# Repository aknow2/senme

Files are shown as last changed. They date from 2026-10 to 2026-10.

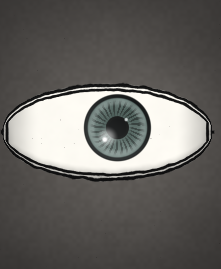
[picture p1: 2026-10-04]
simulator/images/s1/flipbook-frame-024.png

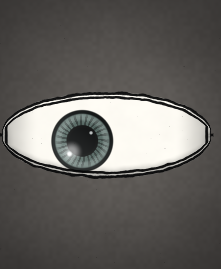
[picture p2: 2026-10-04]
simulator/images/s1/flipbook-frame-028.png

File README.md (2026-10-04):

# Senme

Senmeの機構設計・ファームウェアと、球体リソファン作成用のsimulatorをまとめたフォルダです。

- ルートの `.scad`・`.stl`・画像、`BOSL2/`、`octagonal_bell/`、`firmware/` などは `../6ro_art/senme` からコピーしています。
- `simulator/` は `../360li/experimental` を元にした独立したWebアプリです。必要な共通コード・依存関係の設定・テストをすべて内包しています。

## simulatorの起動

```sh
cd simulator
npm ci
npm run dev
```

http://127.0.0.1:5174/ を開いてください。詳しい操作・確認方法は [simulator/README.md](simulator/README.md) を参照してください。

## 機構設計とファームウェア

OpenSCADの設計は同梱の `BOSL2/` を使用します。
ファームウェアの操作・書き込み方法は [firmware/README.md](firmware/README.md) を参照してください。

## 公開対象と通信の注意

実機MACアドレスのメモ、ビルド成果物、STL、作業用の `tmp/`・`output/`、秘密情報を含むローカル設定は公開対象外です。BOSL2のライセンスは [BOSL2/LICENSE](BOSL2/LICENSE) を参照してください。

現在のESP-NOW通信には暗号化・送信元認証がなく、ブロードキャストの開始指令も受け付けます。無線が届く第三者の指令で待機中のモーターが始動する可能性があります。

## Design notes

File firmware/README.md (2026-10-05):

# SENME ESP32 コントローラー

各モードの現行動作・時間配分・操作仕様は[動作仕様書](動作仕様書.md)を参照してください。

MPU6050の揺れでESP-NOWの `START` を送る別ESP32用スケッチは
[sense_sender](sense_sender/README.md) を参照してください。
書き込みは `./firmware/flash.sh --target sense_sender --port <送信側ポート>` で実行できます。

LEDライトとブラシ付きDCモーターを、それぞれNチャネルMOSFETで制御するArduinoスケッチです。
対象は **通常のESP32（ESP32-WROOM搭載DevKit等）／Arduino-ESP32 3.x** です。
使用ボードは [ELEGOO ESP-32 開発ボード USB-C／CP2102・2個セット（B0FT2SJH3H）](https://www.amazon.co.jp/dp/B0FT2SJH3H) です。
商品写真のESP32-WROOM系モジュールとD25・D26・D27・D32・D33の印字を確認し、既存のピン設定で対応しています。
実機確認は未実施です。ESP32-C3、S2、S3などはこのスケッチの対象外です。負荷の型番は未確定のため、電力側は以下の前提・例です。

## 動作

電源投入時は保存値を読み、ESP-NOWの受信待機から開始します。ボタンを短押しして離すたびに、
「シーケンス → 編集1 → 編集2 → ESP-NOW → シーケンス」の順で切り替わります。
シーケンスへ戻る際も①から再開します。シーケンス・ESP-NOWモード中のロータリー操作は無効です。

| 区間 | 時間 | LED | モーターPWM出力率 |
| --- | --- | --- | --- |
| ① | 20秒 | 5秒周期のsin波で0→100→0%。4周期 | 0% |
| ② | 15秒 | 明るさ0%から100%へ直線的にフェードイン | 55%から設定値まで直線的に上昇 |
| ③ | 60秒 | 設定した点灯時間で点滅 | 設定値を維持 |
| ④ | 15秒 | 設定した点灯時間で点滅（補完した仕様） | 設定値から55%まで直線的に下降し、最後に即0% |

合計110秒で①へ戻ります。④の終了でモーター出力を0%・LEDを消灯し、直ちに①の0%から明滅を再開します。追加の消灯待機時間はありません。
①の式は `輝度 = (1 - cos(2π × 経過時間 / 5秒)) / 2` で、位相をずらしたsin波です。

開始時はPWM出力を55%にし、15秒かけて設定最大値へ上げます。設定最大値が55%以下の場合は、その設定値を開始時から維持します（0%設定なら出力しません）。この開始処理はシーケンス・Motor Edit・ESP-NOWに共通です。

### 編集1：LEDの点灯時間

- 周期は55.55ms固定（約18.0018Hz）。厳密な18Hzの周期は約55.5556msですが、指定の55.55msを使用しています。
- 時計回り1クリックで点灯時間を0.5ms増加、反時計回りで0.5ms減少します。
- 範囲は0〜55.55ms。0msは消灯、55.55msは連続点灯、その間は100%の明るさでパルス点灯します。
- 例えば5.0msなら「5.0ms点灯＋50.55ms消灯」です。変えるのは点滅の周期ではなく、周期内の点灯時間です。
- 初期値は5.0ms。モーター出力は0%です。

点灯時間は0.5ms刻みで55.5msまで調整でき、その次が連続点灯の55.55msです。旧設定の56ms連続点灯は読み込み時に55.55msへ移行します。

### 編集2：モーター最大出力

- 時計回り1クリックで1%増加、反時計回りで1%減少します（刻み幅の補完仕様）。範囲は0〜100%、初期値は55%です。
- 入ってから15秒で55%から設定値へ加速します。ロータリー操作は設定値へ反映し、加速中は経過時間に応じた割合を出力します。
- 終了時は現在の出力から15秒かけて55%まで下げ、その後すぐ0%にします。停止完了までSTART受信・モード切替は無効です。
- LEDは加速中の15秒間は明るさ0%から100%へ直線的にフェードインし、加速完了後に編集1の設定で点滅します。
- 出力率は回転数ではありません。低出力で始動しない場合や、負荷によって回転数が変わる場合があります。

### ESP-NOW：実行メッセージで60秒動作

編集2からボタンを短押しすると、LEDを点滅させたまま15秒かけてモーターを減速してからOFFにします。停止完了後にSTART受付を開始し、LEDはシーケンス①と同じ5秒周期のフェードイン・フェードアウトを繰り返して待機します。
フェードは明るさ0%から開始し、30秒を超えてもSTARTを受信するまで継続します。
起動時もESP-NOW待機に入り、STARTを受信するまでモーターは停止したままです。ESP-NOW以外のモードでは実行メッセージを破棄します。

| 受信後の区間 | モーターPWM出力率 | LED | 実行メッセージ |
| --- | --- | --- | --- |
| 0〜15秒 | 55%から編集2の設定値まで直線的に上昇 | 明るさ0%から100%へ直線的にフェードイン | 破棄 |
| 15〜45秒 | 設定値を維持 | 編集1の設定で点滅開始 | 破棄 |
| 45〜60秒 | 設定値から55%まで直線的に下降し、最後に即0% | 同上 | 破棄 |
| 停止後0〜3秒未満 | 0%で待機 | 明るさ0%から5秒周期のフェードを再開 | 破棄 |
| 停止後3秒以降 | 0%で待機 | フェードを継続 | 次の実行を受付 |

加減速を含めて合計60秒です。START受信後はシーケンス①の20秒間の明滅を挟まず、直ちに加速へ移ります。
待機中の有効なメッセージ1件だけを処理し、動作中のメッセージを
後から実行するために蓄積しません。受信コールバックでは待機状態を確認してから本文を調べ、
動作中は本文の解析も行いません。無線自体は有効なままで、アプリケーション側で破棄します。

メイン処理がモーターPWMを0%にし、LEDをフェードへ切り替えた時点から3秒間はSTARTを破棄し、その後に受付を再開します。この間のSTARTは予約しません。起動時とMotor Editからの移行時には、この3秒待機を設けません。停止後の3秒間も短押しでシーケンスへ移れます。
実際の軸の停止を検知しているわけではなく、惰性で回る可能性があります。
動作中のボタン短押しは無効です。待機に戻ったら短押しでシーケンスへ移れます。
ESP-NOWモードではロータリー操作・長押し保存は無効で、編集1・2の設定を使用します。

#### 送信側の設定

- Wi-Fiチャンネル：**1**（スケッチの `ESPNOW_CHANNEL` で変更可能）。送受信側を同じチャンネルにします。
- 宛先：起動ログの `ESP-NOW: MAC=...` に表示される受信側STA MACアドレス。
- メッセージ：ASCIIの **`START`**、5バイト。終端NULを含む6バイトも許可します。
  改行付き、JSON、小文字の `start`、その他のデータは実行しません。
- 暗号化なし。送信側では宛先をESP-NOW peerに登録して送ります。ブロードキャストも受け付けます。
  送信元MACの制限やアプリケーションの実行受付ACKはありません。
- ルーターへの接続は不要です。USBモニターは引き続き `dtr=off,rts=off` を使用します。

送信側でWi-Fi／ESP-NOWの初期化・同一チャンネル設定・宛先peer登録が済んでいる場合の送信例：

```cpp
const uint8_t command[] = {'S', 'T', 'A', 'R', 'T'};
esp_now_send(receiverMac, command, sizeof(command));
```

送信成功の通知だけでは、受信側が動作を開始したとは判断できません。
受信側が動作中なら破棄されます。また、待機に戻った後に届く再送は新しい実行要求になります。

シリアルログは `READY` → `RUNNING (60 seconds)` →
`STOPPED; COOLDOWN (3 seconds; START ignored)` → 3秒後に `READY (waiting for START)` の順で表示されます。

参考：[Espressif ESP-NOW API](https://docs.espressif.com/projects/esp-idf/en/v5.5/esp32/api-reference/network/esp_now.html)。

### 3秒長押しで保存

編集モードで3秒押し続けると、そのモードの設定だけを内蔵フラッシュへ1回保存します。
離してもモードは切り替わりません。シーケンス・ESP-NOWモード中の長押しは無効です。
保存せずに変更した値も、電源が入っている間はモードをまたいで使用します。
再起動すると最後に保存した値へ戻ります。

ESP32向けの `Preferences`（NVS）をEEPROMの代わりに使います。追加のEEPROM部品は不要です。
保存成功時はシリアルモニターに `SAVED`、失敗時は `SAVE FAILED` を表示します。
保存成功時はLEDを明るさ100%で約3Hz、1秒間に3回点滅させます（約167ms点灯／約167ms消灯）。終了後は現在のモードのLED表示へ戻ります。保存失敗時は確認点滅を行いません。確認点滅中もモーター制御は継続します。

## 配線例

スケッチ先頭の定数でピン番号を変更できます。各GPIOは3.3V信号です。

| ESP32端子 | ELEGOO基板の印字 | 接続先 |
| --- | --- | --- |
| GPIO25 | D25 | LED用MOSFETのゲートへ100〜330Ωの直列抵抗を介して接続 |
| GPIO26 | D26 | モーター用MOSFETのゲートへ100〜330Ωの直列抵抗を介して接続 |
| GPIO32 | D32 | エンコーダーA / CLK |
| GPIO33 | D33 | エンコーダーB / DT |
| GPIO27 | D27 | エンコーダーボタン / SW |
| GND | GND | 各MOSFETソース、負荷電源マイナス、エンコーダーCOM、ボタンの反対端 |
| 3.3V | 3V3 | 電源端子のあるエンコーダーモジュールのVCC（3.3V対応品） |

番号は基板の端から数えた位置ではなくGPIO番号です。例えばコードの `25` は基板の `D25` に対応します。
モード切替にはエンコーダーに付属するボタンを使います。基板上の `BOOT`・`EN` ボタンとは別です。

LEDとモーターの各負荷について、`負荷電源＋ → 負荷＋ → 負荷− → MOSFETドレイン` と接続します。
MOSFETソースはGNDへ、ゲート–ソース間には10kΩ程度のプルダウン抵抗を入れ、起動中もOFFに保ちます。
MOSFETは **ゲート電圧2.5〜3.3Vでのオン抵抗が仕様に明記されたもの** を、負荷電流・電圧・発熱に合わせて選定してください。
しきい値電圧だけでは選定できません。PWM対応MOSFETモジュールを使う場合も、3.3V入力・HIGHでONの仕様を確認します。

モーター両端には逆起電力を逃がすフライバックダイオードを並列接続します。
**カソード（帯側）はモーター＋、アノードはモーター−（ドレイン側）** です。
モーターの始動・拘束電流に対応する電源、MOSFET、ダイオードが必要です。
モーターの電力配線はESP32基板を経由させず、電源付近でGNDを共通化します。
電源付近のバルクコンデンサとモーター端子間のノイズ対策コンデンサも、使用モーターに合わせて設けてください。

LEDは電流制限付きのDCライト／LEDストリップを想定しています。裸のLEDやパワーLEDには適切な電流制限回路が別途必要です。
LED・モーターの負荷電力はESP32のGPIOや3.3V端子から供給しません。
この配線はブラシ付きDCモーター用です。サーボ・ステッピング・ブラシレスモーターには別の駆動回路が必要です。

エンコーダー入力は内部プルアップを使用し、接点がGNDへ落ちる方式です。5Vにプルアップされた信号を直接接続しないでください。
時計回りで値が減る場合は `ENCODER_DIRECTION = -1` に変更します。
2クリックで1回しか変わらない機種では `ENCODER_EDGES_PER_CLICK` を4から2へ変更します。

## Arduino CLIでの書き込み（macOS）

対象は `ESP32 Dev Module`、FQBNは `esp32:esp32:esp32` です。
Arduino-ESP32はコンパイル確認済みの **3.3.8** を使用します。
追加ライブラリは不要です。Preferences、LEDC、RMT、Wi-Fi、ESP-NOWはESP32コアに含まれます。

### 自動実行スクリプト

リポジトリのルート（`senme`）から実行します。
先にLED・モーターの負荷電源を切り、ESP32をUSB接続してください。
開いているシリアルモニターは `Ctrl+C` で終了します。

```sh
./firmware/flash.sh --port /dev/cu.usbserial-0001
```

スクリプトはArduino CLIの準備 → ESP32コア3.3.8の準備 → コンパイル → 書き込み →
シリアルモニター起動を順に実行します。CLIがない場合は、インストール済みのHomebrewを使用します。
コアが既に3.3.8なら再インストールしません。ポートは実機に合わせて指定してください。
別の作業ディレクトリから実行しても動作します。

```sh
# ポート一覧の確認
arduino-cli board list

# 書き込みまで実行し、モニターを開かない
./firmware/flash.sh --port /dev/cu.usbserial-0001 --no-monitor

# 実機に書き込まず、環境準備とコンパイルだけ実行
./firmware/flash.sh --build-only

# 環境変数でポートを指定することも可能
export ESP32_PORT=/dev/cu.usbserial-0001
./firmware/flash.sh
```

### 手動で実行する場合

1. 初回のみCLIとボード定義を準備します。CLIが導入済みなら `brew install` は不要です。

```sh
brew install arduino-cli
arduino-cli config add board_manager.additional_urls \
  https://espressif.github.io/arduino-esp32/package_esp32_index.json
arduino-cli core update-index
arduino-cli core install esp32:esp32@3.3.8
```

2. USB接続したボードのポートを確認します。ボード名がUnknownでも、ポートとFQBNを指定できます。

```sh
arduino-cli board list
export ESP32_PORT=/dev/cu.usbserial-0001
```

3. `senme` ディレクトリからコンパイル・書き込みします。
   `senme_controller.ino` と `Control.h` は同じフォルダに置きます。

```sh
arduino-cli compile \
  --fqbn esp32:esp32:esp32 \
  --output-dir /tmp/senme-build \
  firmware/senme_controller

arduino-cli upload \
  --port "$ESP32_PORT" \
  --fqbn esp32:esp32:esp32 \
  --input-dir /tmp/senme-build \
  firmware/senme_controller
```

4. **115200 bps・DTR OFF・RTS OFF** でログを開きます。

```sh
arduino-cli monitor \
  --port "$ESP32_PORT" \
  --config baudrate=115200,dtr=off,rts=off
```

接続後に基板の **EN（RESET）を一度押して離す**と、起動ログを確認できます。
BOOTは押しません。初期設定では次の表示が出ます（保存済みの設定があれば数値は変わります）。

```text
Mode: ESP-NOW; click: next mode; hold 3 seconds in edit mode: save
LED: 5.00 ms ON / 55.55 ms period; motor maximum: 55%
ESP-NOW: READY (waiting for START)
```

モニター終了は `Ctrl+C` です。起動後はSTART受信でモーターの加速が始まるため、
配線を確認してから負荷電源を入れてください。

### 文字化け・接続失敗時

- 実機では `baudrate=115200` だけの指定で文字化けし、
  `baudrate=115200,dtr=off,rts=off` の指定とリセットでログ表示を確認できました。
  スケッチ側も `Serial.begin(115200)` です。文字化け時は上記設定で開き直し、ENを押してください。
- 書き込みが `Connecting...` で止まる場合は、BOOTを押したまま書き込みを開始し、転送開始後に離してください。
- ポートがない場合はUSBデータ通信対応ケーブルと接続を確認し、`arduino-cli board list` で再確認してください。
- ポート使用中のエラーが出る場合は、別のターミナルやArduino IDEのシリアルモニターを終了してください。

参考：[Espressifのボード定義の導入手順](https://docs.espressif.com/projects/arduino-esp32/en/latest/installing.html)、
[DTR／RTSと起動・リセットの関係](https://docs.espressif.com/projects/esptool/en/latest/esp32/advanced-topics/boot-mode-selection.html)。

## 時間精度と実機確認

LED点滅はRMTの1MHzタイマーで周期55,550tick、点灯時間500tick刻み（最大55,550tick）として生成します。点灯区間は100%出力とし、キャリアPWMは無効にしています。
設定保存やシリアル表示中もハードウェアが波形を出し続けます。①の調光は1kHzのPWMを使います。
調光と点滅の切替時には、周期・比較値の反映待ちで約55.55ms消灯します。周期自体の精度はボードのクロック精度に依存します。
設定・明るさの更新時は波形を一度停止して新しい周期を開始します。切替時のパルスは短くなる場合があります。一定設定ではハードウェアが自動反復し、保存や通信によるタイミングの揺れを避けます。
モーターは20kHz・10bit PWMです。モード切替と加減速の更新はメインループで行うため、OSのスケジューリング等による遅延があります。

MOSFET1個による制御では出力を0%にしてもモーターは惰性で回転することがあります。
「減速終了後に実際の回転停止を確認してLEDを消す」ことまで必要な場合は、回転検出とブレーキ可能なドライバーを追加してください。
この実装では15秒の減速終了時のPWM出力0%を停止指令と扱っています。
すべての通常停止（シーケンス・ESP-NOW・編集2終了・シーケンスから編集1への切替）は、現在の出力から15秒でPWM出力率55%へ下げ、最後に即0%とします。
開始時の出力が55%以下なら出力を上げずに15秒維持してから0%にします。既に0%ならそのまま停止します。
LED・モーター制御APIなどでエラーが発生した場合も、最後に正常適用した出力から15秒かけて55%へ減速し、その後0%を指令します。55%以下は15秒維持し、既に0%またはモーター未初期化なら直ちにOFFを指令します。異常時はSTART受付を無効化し、停止処理後も自動復帰せずリセット待ちになります。モーターAPI自体の失敗時は減速を保証できず、その旨をログに表示します。最後の0%指令に失敗した場合は、1秒ごとに0%を再試行します。電源断・CPU停止はこの減速処理の対象外です。

- 起動直後はESP-NOW待機となり、モーター出力0%、LEDが5秒周期で明滅し、START未受信なら20秒を超えても停止を維持すること。
- 待機中の短押しでシーケンス①に入り、LEDが5秒周期で4回明滅すること。
- シーケンスへ切り替えてから20秒で加速開始（LEDは15秒で0%から100%へフェードイン）、35秒で設定出力に達して点滅開始、95秒で減速開始、110秒で出力0%になり①へ戻ること。
- シーケンスから編集1へ切り替えると15秒で55%まで減速後、即0%になること。減速中の再切替は無効になること。
- オシロスコープ等で55.55ms周期と0.5ms刻みの点灯時間を確認すること。0msと55.55msの端点も確認すること。
- 編集2の開始時は15秒で加速し、終了時は15秒で55%まで減速して即0%になること。減速中のSTARTは破棄されること。
- 編集2で出力が1%刻みで変わり、0〜100%に収まること。低出力時の始動・発熱も確認すること。
- 長押しで `SAVED` が1回出て、LEDが100%で1秒間に3回点滅して元の表示へ戻ること。離してもモードが変わらず、点滅中もモーター制御が続くこと。保存失敗時は確認点滅しないこと。
- 各設定を保存して電源を入れ直すと復元されること。未保存変更は復元されないこと。
- モーター駆動中にエンコーダーの誤カウントやESP32の再起動が起きないこと。
- ESP-NOW待機中はLEDだけが5秒周期でフェードし、30秒を超えてもモーターが動かないこと。停止直後にフェードを再開し、STARTは3秒間破棄した後に受付を再開すること。
- ESP-NOWモードで `START` を送り、15秒加速・30秒維持・15秒減速（55%到達後、即0%）して停止すること。
- 動作中に繰り返し送信しても、延長・再実行されないこと。送信をやめて待機へ戻っても勝手に再開しないこと。
- 待機に戻ってから新しい `START` を送ると再び実行すること。他モードや不正なメッセージでは開始しないこと。
- ESP-NOW動作中の短押しでモードが変わらず、待機中なら切り替えられること。
- 無線通信中もLEDの周期、モーターの加減速、電源の安定性に問題がないこと。

ホスト側のロジックテストは、`firmware` フォルダで次のように実行できます。

```sh
c++ -std=c++17 -Wall -Wextra -Werror tests/control_test.cpp -o /tmp/senme-control-test
/tmp/senme-control-test
```

検証済み：Arduino-ESP32 3.3.8／`esp32:esp32:esp32` のコンパイル、および上記ロジックテスト
（シーケンス境界・加減速・設定範囲・ボタンのチャタリングと長押し・ESP-NOW実行状態／受信破棄／停止後3秒の受信抑止と再受付・時計の桁あふれ）。
実機の回転・波形・電源ノイズ・保存復元・ESP-NOW送受信は未確認です。

## 参照

- [Espressif: PreferencesはEEPROMの代替、電源断後も保持](https://docs.espressif.com/projects/arduino-esp32/en/latest/tutorials/preferences.html)
- [Espressif: LEDC API](https://docs.espressif.com/projects/arduino-esp32/en/latest/api/ledc.html)
- [Espressif: MCPWMタイマー・比較器・出力制御](https://docs.espressif.com/projects/esp-idf/en/v5.5/esp32/api-reference/peripherals/mcpwm.html)

## ボタン誤判定の調査・修正（2026-10-03）

ボタンの読み取りが途切れた間に離された短押しを、経過時間だけで長押し保存に分類する経路を再現し、修正しました。100 msを超えるサンプリング中断が操作中にあった場合、その操作を破棄し、25 ms以上の安定したリリース後に次の押下を受け付けます。中断中の押下時間は確認できないため、保存や遅延したモード切替を実行しません。

シリアルには `BUTTON: CLICK (… ms)`、`BUTTON: LONG PRESS (… ms)`、読み取り中断時には `BUTTON: sampling gap >100ms…` が出ます。短押しのつもりで `LONG PRESS (3000 ms)` が出る場合は、実際の接点・GPIOの状態も確認が必要です。この修正で実機症状の原因が確定したわけではありません。

モード切替に伴う15秒のモーター停止中、ESP-NOWの受付後〜運転終了までの短押し無効は従来仕様です。無効な操作は予約されません。`Mode change ignored…` のログでボタン判定自体の失敗と区別できます。

## モード切替のLED通知（2026-10-03）

短押しによるモード切替が成立すると、LEDが短く2回点滅します。消灯100 ms → 点灯80 ms → 消灯100 ms → 点灯80 ms → 消灯140 ms、合計0.5秒で通常の表示に戻ります。Save成功時の「約1秒で3回点滅」と区別できます。

停止中・ESP-NOW運転中などで短押しを無視した場合は、切替通知を出しません。通知はLEDだけを一時的に上書きし、モーター制御・ボタン読取り・ESP-NOW処理は継続します。通知の間もシーケンスの時間は進みます。連続して切り替えた場合は最新の通知を最初から表示し、Save通知中に切り替えた場合も切替通知へ置き換えます。

## ボタン入力の極性（2026-10-04）

実機で短押しだけを行った際、旧判定（LOWで押下）では2.4〜2.8秒のCLICKや3秒のLONG PRESS、意図しないSaveが記録されました。押していない時間を押下時間として数えている可能性が高いため、このController用の `BUTTON_PRESSED_LEVEL` を `HIGH` に変更しています。実機で短押し時間と無操作時のログを確認してください。起動ログにはGPIO27のレベルと設定した押下レベルを表示します。

GPIO27の `INPUT_PULLUP` は継続しています。通常の「押すとGNDにつながる」常開スイッチを使う場合は `BUTTON_PRESSED_LEVEL = LOW` にしてください。今回の変更は自動極性判定ではありません。

修正版をControllerへ書き込み、起動時GPIO27=LOWを確認しました。実機の短押し3回は145 ms・174 ms・197 msのCLICKとして認識され、ESP-NOW→SEQUENCE→EDIT 1→EDIT 2へ切り替わりました。この確認中にLONG PRESSやSaveの誤検出はありません。保存設定（LED 1.50 ms、モーター最大93%）は保持しています。

## 点滅時の明るさ（2026-10-04）

点滅時の明るさを100%へ戻しました。RMTのキャリアPWMは無効にし、点灯区間は連続HIGH、消灯区間はLOWです。周期55.55 msと設定点灯時間は維持します。点灯時間1.50 msでは周期全体の平均出力は約2.7%です。
開始フェードは15秒で0%→100%、モーター開始・停止は55%です。

## START受信時の始動通知

ESP-NOWのSTART受付後、モーターを停止したままLEDを1秒間に6回点滅させます。100%点灯と消灯を約83msずつ繰り返し、その後に従来の60秒運転（15秒加速・30秒維持・15秒減速）を開始します。通知中も追加STARTと短押しは無効です。ログは `START accepted; 6 flashes (1 second), motor OFF` → `RUNNING (60 seconds)` の順に表示されます。

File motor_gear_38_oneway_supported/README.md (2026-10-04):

# 旧ワンウェイクラッチ：駆動側ストッパー付きハブ

`motor_gear_38_oneway_supported_hub.stl` が交換用です。旧版の `motor_gear_38_oneway_gear.stl` と `motor_gear_38_oneway_cover.stl`、使用中の金属ねじを再利用します。鼓形ローラー版用ではありません。

## 変更点

バネ爪の自由端の背後に、中央ハブと一体の固定受けを3箇所追加しました。爪が駆動反力で時計回り側へ逃げると受けに当たる構成です。爪との初期隙間は半径24.6 mm付近で約0.34 mm（0.8度）。受けの最大半径は25.2 mmで、外ギアの内歯先端半径26 mmより0.8 mm内側です。

爪先形状、バネ厚1.2 mm、D穴、全高13 mm、蓋との隙間は旧版と同じです。回転方向も旧版と同じです。爪の内側を全面的に埋めず、半径内向きの退避空間を残しています。

## 印刷と交換

1. 交換用ハブだけPETGで印刷します。元のハブと同じ向きで、張り出し下面にサポートを使います。
2. サポートとバリを除去します。特に爪とストッパーの隙間が印刷でつながっていないことを確認します。
3. 蓋を外してハブを交換し、既存の蓋と金属ねじで組み戻します。
4. まず手で駆動方向の噛み込みと、逆方向の空転を旧版と比較します。その後、低負荷からモーター駆動時の歯飛び音を確認します。

## 確認済み範囲と限界

幾何学チェックは `verify_supported.scad` と `geometry_checks.json`、STLチェックは `mesh_checks.json` を参照してください。

- 初期位置で爪と受けが重ならないこと。
- 爪を剛体として1度時計回りにずらすと受けに当たること。
- 爪を半径内向きに0～2.2 mm平行移動させた指定経路で、受けと重ならないこと。
- 組立初期位置で、ハブと既存のギア・蓋に意図しない重なりがないこと。

**指定した剛体移動経路の確認は、実際のバネ変形や荷重解析とは異なります。** 曲がる爪が空転時にも受けに当たり、抵抗が増える可能性があります。歯飛びの改善、空転抵抗、保持トルク、疲労寿命は実機未検証です。改善しない、または空転が重くなる場合は、無理に回し続けず旧ハブと比較してください。

元のCAD・STLは変更していません。このフォルダの `motor_gear_38_oneway.scad` は旧版の参考コピーです。新しい編集対象は `motor_gear_38_oneway_supported.scad` です。歯形生成は親フォルダの `BOSL2` を参照します。STLの印刷にはBOSL2は不要です。

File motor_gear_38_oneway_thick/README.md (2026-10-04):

# 旧版ワンウェイクラッチ：バネ腕1.4mm比較用ハブ

印刷するのは `motor_gear_38_oneway_thick_hub.stl` だけです。旧版 `motor_gear_38_oneway_gear.stl`、同cover、金属ねじを再利用します。

旧版のバネ腕の幅を1.2mmから1.4mmへ増やしました。同じパラメータを使うアンカー先端も太くなります。ストッパーはありません。爪先形状、D穴、全高13mm、回転方向は元のままです。

旧版と同じ印刷姿勢で、張り出し下面にサポートを使用してください。バネ腕の周囲のサポート・バリを取り除き、取り付け後は手回しで元のハブと比較してください。

カチカチ音は歯飛び以外に、ターンテーブルの惰性による追い越し空転でも発生します。重量だけで原因は断定できません。一定速のモーターを慣性だけで持続的に追い越すわけではありませんが、モーター側が減速・速度変動した瞬間に出力側が先行することは考えられます。

正常な追い越し空転が原因なら、厚肉化は必要とは限りません。バネを太くすると空転抵抗が増える可能性があります。駆動中に中央ハブが外ギアを追い越すのか、外ギアがハブを追い越すのかを目印・動画で確認してください。改善効果・空転抵抗・耐久性は実機未検証です。

CADソースは親フォルダの `motor_gear_38.scad` と `BOSL2` を参照します。元ファイルは変更していません。

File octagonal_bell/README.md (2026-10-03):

# 正八角形の電子鈴

参考画像をもとにした試作モデル。単位は mm。OpenSCAD 2021.01 で使用でき、外部ライブラリは不要です。

## 開き方

`octagonal_bell.scad` をOpenSCADで開き、F5でプレビューします。
先頭の `part` を変更して表示を切り替えます。

| part | 表示 |
| --- | --- |
| assembly | 完成形 |
| section | 前半分を取り除いた断面・収納例 |
| exploded | 分解表示 |
| print | 印刷部品4点を平面上に配置 |
| body / lid / tray / shelf | 本体／上蓋／基板トレー／電池棚を個別表示、底面Z=0 |
| ball | 鈴玉の参考形状、底面Z=0 |

印刷には同梱の `body.stl`、`lid.stl`、`tray.stl`、`shelf.stl` を使用できます。寸法を変えた場合は各部品をF6でレンダリングしてSTLを再出力してください。完成表示の電池・基板は寸法確認用の箱です。

## 寸法と構造

- 正八角形の対辺180、対角約194.8、ロープ取り付け部を含め全高148.4（元の135から13.4延長）。
- 壁厚3、胴体の合わせ面Z=91.4、上蓋との隙間0.35、差し込み部の片側余裕0.3。
- Bodyの底面対辺は約128.3。サポートを減らすため旧100から拡大し、下部外周は八角形の頂点方向でも鉛直から45度以下の張り出しにしています。
- 電池135.5 × 69 × 16を中央の棚に横置き。棚の下にESP32 52 × 28 × 12とMPU6050 21 × 16 × 5の参考外形を横並びで配置。
- トレー上面から電池棚下面までの有効高さは30mm（`electronics_clearance`）。トレー底面Z=48を維持して電池棚下面をZ=80.4に上げ、合わせ面・肩・天井も13.4mm上げています。支柱の全高は32.4mm。基板の参考外形には実物の10mmピンやコネクター・配線を正確には反映していません。
- 下部は直径25の鈴玉用空間。基板トレーが電子機器と鈴玉を隔てます。
- 底面中央の音穴は幅4、全長90、両端の丸穴は直径10。ロープ穴は幅19 × 高さ14。
- 上蓋は前後2箇所のM3 × 35ねじと六角ナットで固定。本体側は直径3.4の通し穴と、内側から横差しできるナット受け（対辺6.0・高さ2.8）があります。ナット受け上面は合わせ面から19mm下（Z=72.4）、下面は21.8mm下（Z=69.6）です。外装の外側には開口しません。
- 電池棚は4箇所のM3ねじと六角ナットでトレーの支柱に固定。支柱はトレー底面まで直径3.4の貫通穴、裏面には対辺6.0・深さ2.6の六角ナットくぼみがあります（各部のナットは対辺5.5・厚さ2.4を想定）。

画像の対辺150では、厚さ3の壁と矩形の電池の角の間に余裕がありません。現在のモデルは対辺180に設定しています。電池外形は八角形に収まりますが、コネクター・ケーブルの曲げ・ケースの突起は含めていません。実物に応じて `battery` と `body_width` を調整してください。基板寸法・高さも仮定値です。

## 組み立て

1. トレー・電池棚を入れる前に、本体の前後の固定部へ内側の横穴からM3六角ナットを1個ずつ奥まで差し込み、ねじ穴を合わせます。ナット受けは電池棚より下にあるため、先に入れてください。その後、本体に直径25程度の鈴玉を入れます。
2. 基板を絶縁スペーサーや結束バンドでトレーに固定します。基板固有の取り付け穴は未設定です。
3. 本体に入れる前に、トレー裏面の4箇所の六角くぼみにM3ナットを入れ、電池棚の上からねじを通して支柱に固定します。棚上面からトレー裏面までは34.8mmです。頭の下から測って35mmのM3ねじ（皿ねじ以外・座金なし）なら裏面から約0.2mm突き出す設計です。実物のナット・ねじとの適合を確認してください。くぼみの余裕は `tray_nut_af` と `tray_nut_depth` で調整できます。
4. 棚を固定したトレーを本体内周の受けに載せます。
5. 電池を棚の長穴を使った結束バンドで固定し、奥側のケーブル口から配線します。
6. 上蓋の差し込み部を入れ、頭径6.6未満のM3 × 35で固定します（皿ねじ以外・座金なし）。ねじ先端は合わせ面から23mm下まで入り、ナット受け下面を1.2mm通過します。閉じるまでナットが横穴から抜けないよう本体を水平に保ってください。挿入余裕は `lid_nut_af` と `lid_nut_height` で調整できます。
7. ロープを上部の穴に通します。

トレー自体は受けに載せる方式です。振ったときの浮きやがたつきは試作確認の対象で、必要なら蓋側との間に緩衝材を追加してください。

30mmの隙間に変更する前の本体は高さが足りないため、新しいトレーと組み合わせる場合は本体も再印刷してください。トレー受けの高さと鈴玉の空間は維持しています。底に置いた参考鈴玉の上端とトレー下面の隙間は20mmです。

## 印刷と確認範囲

### 必要なねじ・ナット

| 用途 | 部品 | 数量 |
| --- | --- | --- |
| 上蓋と本体 | M3 × 35 なべ小ねじ（全ねじ、頭径6.6未満） | 2本 |
| 電池棚とトレー | M3 × 35 なべ小ねじ（全ねじ） | 4本 |
| 上蓋2箇所＋トレー4箇所 | M3六角ナット（対辺5.5・厚さ2.4想定） | 合計6個 |

M3 × 35なべ小ねじ6本とM3六角ナット6個に統一しています。座金なしで設計しています。ESP32・センサーの固定ねじは、基板の取り付け穴が未確定のため含みません。ナット式の上蓋固定に変更する場合、本体は新しい `body.stl` で印刷してください。

本体・トレー・棚はSTLの向きで底面を下にします。蓋はスライサーで差し込みリップ、天井、ロープ穴の下面を確認し、必要なサポートを付けてください。全パーツのサポート不要は保証していません。

### Bodyのサポートなし印刷向け変更（2026-09-26）

今回の変更はBodyのみです。蓋・トレー・電池棚の形状とSTLは変更していません。既存のM3×35ねじ・ナットを使い、Bodyだけ差し替えられます。

- トレー受けの下面に高さ6mmの斜面を追加。受け上面Z=48と受け幅を維持しています。
- 蓋用ネジ支柱の下端を壁から伸びる斜面に変更。ネジ位置、支柱上部の直径12mm、ナット挿入口の位置を維持しています。
- ナット穴の天井には0.3mmずつ2段の逃げを追加。最初は左右へ最大6mm、次は前後へ3.4mmを橋渡ししてから丸いネジ穴へつなぎます。ナットを受ける前後の平らな座面を残し、除去が必要な膜は設けていません。
- 底面の対辺を100mmから約128.3mmへ拡大。上部の対辺180mm、高さ91.4mm、音穴の寸法は維持しています。鈴室の下部形状が変わるため、音は実物で確認してください。

印刷時はSTLの底面を下にし、**サポートOFF、積層0.2mm以下**を想定しています。可変積層を使う場合もナット天井付近（Z=72.4〜73.0mm）は0.2mm以下にしてください。スライサーのプレビューで、最初の天井ブリッジが横穴の左右の壁を結んでいることと、次の段が前後を結んでいることを確認します。最初のブリッジを穴の奥行き方向へ走らせると片端が空中になるため、必要ならその層のブリッジ方向を調整します。

短いブリッジをサポートなしで印刷する設計ですが、成功は材料・冷却・スライサー設定にも依存します（[Prusaのブリッジ印刷解説](https://help.prusa3d.com/article/poor-bridging_1802)）。実機でのスライス・印刷は未確認です。

検証：BodyのCGALレンダリングは `Simple: yes`。STLは閉じた一体のメッシュで、鉛直から45度を超える下向き面は接地面とナット天井のブリッジ部分だけであることを確認しました。蓋・トレー・電池棚のCSGは変更前と一致し、Bodyとの体積干渉はありません（トレーはZ=48で面接触）。新しい断面は `body_supportless_section.png` を参照してください。既存の `preview.png`、`section.png`、`bottom.png` は変更前の参考画像です。

OpenSCADで4部品のCGALレンダリングとSTL出力を実行し、すべて `Simple: yes` を確認済みです。外観と断面のプレビューも作成しています。実印刷、ねじの保持力、吊り部の荷重試験、電子機器の実装は未確認です。防水構造ではありません。樹脂製の殻は金属鈴とは異なる音になるため、音質は試作で調整してください。

再出力例：

```sh
openscad -o body.stl -D 'part="body"' octagonal_bell.scad
```

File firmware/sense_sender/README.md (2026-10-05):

# sense_sender：揺れでSTARTを送信

ESP32-WROOM系の開発ボードとMPU6050を使い、大きな揺れを検知したら
ESP-NOWでASCIIの `START`（5バイト、改行なし）を1回送信します。
Arduino-ESP32 **3.3.8** 用です。Wire・Wi-Fi・ESP-NOWはコア付属で、追加ライブラリは不要です。
モーターを制御する `senme_controller` とは別のESP32へ書き込んでください。

## 配線

3.3V電源・3.3V I2C信号に対応したMPU6050モジュールを使用します。
モジュールの電源仕様・端子表記を確認してください。

| 送信側ESP32 | MPU6050モジュール |
| --- | --- |
| 3V3 | VCC（3.3V対応電源入力） |
| GND | GND |
| GPIO21 / D21 | SDA |
| GPIO22 / D22 | SCL |
| GND | AD0（アドレス0x68） |

INT・XDA・XCLは接続不要です。SDA/SCLは3.3Vへのプルアップが必要です。
モジュールに実装済みなら追加不要、なければ各線に4.7kΩ程度を追加します。
AD0を3.3Vに接続する場合はコードの `MPU_ADDRESS` を `0x69` にします。

## 検知の動作

1. 起動後、静かな状態が3秒続くと `ARMED`（検知可能）になります。
2. 約10msごとに加速度を読み、`abs(sqrt(x² + y² + z²) - 1)` をg単位で計算します。
3. その値が **0.45gを超える読み取りが2回連続**すると、`START` を1回送ります。0.45gちょうどでは送信しません。
4. 揺れが収まり、0.25g以下が3秒続き、かつ前回の送信から3秒以上経過すると再び検知可能になります。両方の待ち時間は重なり、合計6秒待つ必要はありません。

この数値は初期値です。取り付け位置や揺らし方に応じて調整してください。
静止中の重力1gを差し引くため、静止した向きが変わるだけでは反応しません。
角速度や振れ幅そのものを判定する方式ではなく、加速度の変化を検知します。
落下・衝撃でも反応し得ます。加速度レンジは±8g、ローパスフィルターは44Hzです。

揺れ続けても連送しません。送信失敗時にも自動再送せず、静止してからの次の揺れで送ります。
センサー読み取り失敗時は送信を抑止し、有効な読み取りと静止期間を確認してから再開します。
起動時にセンサーの識別・設定に失敗した場合はエラーで停止するので、配線確認後にENで再起動してください。

## 通信設定

`sense_sender.ino` の先頭で指定します。

- `ESPNOW_CHANNEL = 1`：受信側と一致させます。Wi-Fiルーターへの接続は不要です。
- `RECEIVER_MAC = FF:FF:FF:FF:FF:FF`：初期値はブロードキャストです。
  同じチャンネルで待機中の対応受信機すべてが反応します。
  1台だけに送る場合は、受信側の起動ログに出るSTA MACアドレスへ変更してください。

例えば受信側MACが `AA:BB:CC:11:22:33` なら、次のように変更します（この値は例です）。

```cpp
const uint8_t RECEIVER_MAC[6] = {0xAA, 0xBB, 0xCC, 0x11, 0x22, 0x33};
```

暗号化・アプリケーションの受付ACKは使用しません。ログの `START queued` は送信要求受付、
`link OK` は無線送信結果であり、モーターの実行開始を保証しません。
特にブロードキャストは受信機が不在でも成功扱いになり得ます。

受信側は **ESP-NOWモード**にしてください。動作中60秒と停止後3秒間の受信破棄は受信側で行い、その後に次のSTARTを受け付けます。
その期間の揺れによる送信は実行されず、後で再送もされません。
受信側が `READY` に戻った後、新たに揺らすと再実行できます。

## 書き込みとログ

`senme` ディレクトリから、送信側ESP32のUSBポートを確認して実行します。
受信側と送信側を両方USB接続している場合は、片方ずつ接続してポートを確認してください。

```sh
arduino-cli board list

# /dev/cu.usbserial-0001 は送信側の実際のポートへ置き換える
./firmware/flash.sh --target sense_sender --port /dev/cu.usbserial-0001

# コンパイルだけ
./firmware/flash.sh --target sense_sender --build-only
```

`--target` を省略すると受信側 `senme_controller` が選ばれます。
スクリプトは環境準備、コンパイル、書き込み、115200 bps・DTR OFF・RTS OFFでのログ表示を行います。
接続後にENを押すと起動ログが見られます。終了は `Ctrl+C` です。

```text
Keep still for 3 seconds to arm; shake strongly to send START.
ARMED: waiting for shake
SHAKE: 3.10 g; START queued (ESP_OK)
ESP-NOW: link OK (not execution acknowledgement)
```

## 感度調整と確認

`ShakeDetector.h` の定数を変更して書き込み直します。

| 定数 | 初期値 | 意味 |
| --- | --- | --- |
| `kTriggerG` | 0.45 | 小さくすると弱い揺れでも反応 |
| `kTriggerSamples` | 2 | 閾値を超える連続読み取り回数 |
| `kQuietG` | 0.25 | 静かな状態とみなす上限。`kTriggerG` より小さく設定 |
| `kQuietMs` | 3000 | 再検知の前に必要な静止時間 |
| `kMinSendIntervalMs` | 3000 | 送信の最小間隔 |

`motion=... g` は500msごとの値です。短い揺れのピークはこの定期ログには出ない場合があります。
検知時の `SHAKE` ログにも、その時点の値を表示します。

実機で確認する項目：

- 静止・小さな振動では送信せず、大きく揺らすと1回送信する。
- 揺れを続けても連送せず、一度静止してから揺らすと再送信できる。
- 受信側のESP-NOWモードで60秒動作が始まる。
- 受信側の動作中は揺らしても再実行されず、待機に戻ってからの新たな揺れで実行する。
- I2C配線が外れたときに、読み取りエラーを揺れとして送信しない。

ホスト側の判定ロジックテスト：

```sh
c++ -std=c++17 -Wall -Wextra -Werror firmware/tests/shake_test.cpp -o /tmp/senme-shake-test
/tmp/senme-shake-test
```

コンパイルと判定ロジックのテストを実施。センサー実機での感度・ESP-NOW通信は未確認です。

参考：[Espressif ESP-NOW API](https://docs.espressif.com/projects/esp-idf/en/v5.5/esp32/api-reference/network/esp_now.html)、
[TDK MPU6050レジスタ資料](https://invensense.tdk.com/wp-content/uploads/2015/02/MPU-6000-Register-Map.pdf)。

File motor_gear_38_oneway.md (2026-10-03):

# 38歯ギア・PETGワンウェイクラッチ試作

元の `motor_gear_38.scad` と既存STLは変更しない。新しいSCADは元ファイルの歯車形状・D穴モジュールを参照するので、同じディレクトリに置く。

## 回転方向

上面（SCADの+Z側）から見て、モーターハブを反時計回りに回すと爪が内歯に当たり外側ギアを駆動する。外歯車でつながる112歯ターンテーブルは時計回りになる。モーター停止後は外側ギアだけが反時計回りに追い越し、爪を押し下げて空転する。

モーター軸が下から上へ出ている配置を想定。上下を反転して取り付ける場合は向きを再確認する。`reverse_direction=true`でラチェットと爪を鏡像にできる。

モーター出力軸160 RPMで、ターンテーブルは `160 × 38 / 112 ≈ 54.3 RPM`。モーター軸だけが即座に停止し、外側ギアが160 RPMを維持した瞬間には、爪1本あたり毎秒64回の歯通過となる（24歯）。3本の爪は同位相なので同時に作動する。これは運動学上の計算であり、160 RPMでの耐久性を確認したものではない。

## 部品

| render_part | 内容 |
| --- | --- |
| assembly | 組立状態（既定） |
| open | 蓋を除いた内部表示 |
| exploded | 分解表示 |
| gear | 外側38歯ギア、床、24歯内周ラチェット |
| hub | D穴ハブ、3本の弾性爪、上下ジャーナル |
| cover | 保持カバー |
| layout | 3部品を離して配置 |

歯車の外周と厚さ13 mm、D穴のF7 / 片側すき間0.06 mmは元モデルを使用。カバーはギア上面の凹みに収まる。別途、樹脂向けM2.5ねじ3本が必要。長さ8 mmを想定（蓋1.8 mmを通過後6.2 mmかかる）。下穴径2.2 mmは使用ねじと造形精度に合わせて端材で確認する。通常の機械ねじを無理にねじ込まない。

**ねじ頭は13 mmの本体厚さより上に出る。** 周辺とのすき間を実測すること。カバーはギアとハブの分離を防ぐが、全体がモーター軸から抜けることを防ぐものではない。軸方向の抜け止めは既存と同様に別途必要。

## PETG造形・組立

初期設定は0.4 mmノズル、0.2 mm層厚、壁数4以上を目安にし、スライサー上で幅1.2 mmの弾性腕が連続した線になることを確認する。材料や印刷条件が異なる場合は調整する。

- 外側ギアと蓋：表示された底面を下に置く。通常はサポート不要。
- ハブ：ジャーナル下端を底に置く。高さ2.2 mmから張り出すハブ本体・腕の下面にはサポートが必要。ビルドプレートからのサポートを使い、細い腕を折らないよう除去する。サポート接触面の荒れを取り除き、床との接触を確認する。
- 軸受面・爪・歯の糸引きとバリを取り除く。ハブを外側ギアに入れ、カバーを載せてねじ止めする。ねじの締め付けで蓋を変形させない。
- 軸にはめる前に、ハブを固定して外側ギアを上から見て反時計回りに回す。カチカチと空転し、時計回りでは噛み合うことを確かめる。
- 続いて外側ギアを固定し、ハブの反時計回りで駆動できることを確かめる。まず無負荷・低速で試す。

爪は各120度、内歯は15度間隔。初期形状は爪が谷に入る位置で、駆動開始時の遊びは位相によって最大約1歯分ある。空転は無抵抗ではなく、爪の弾性抵抗・摺動抵抗・クリック音がある。惰性回転の継続時間は実機で確認する。

## 調整と未検証事項

片側のジャーナルすき間は0.3 mm、爪の上下すき間は各0.4 mm。印刷誤差による固着には `radial_gap` / `axial_gap` を調整する。爪先は半径27.65 mm、内歯先は26 mmなので、空転時には概ね1.65 mmの半径方向の退避が必要になる。静止CADは変形前の形状を表し、空転中の弾性変形をシミュレーションしない。

**これは形状試作であり、負荷をかけて使えることを保証した設計ではない。** モーターのトルク、テーブルの慣性、PETGの銘柄が未指定。爪の許容トルク、疲労寿命、クリープ、発熱、摩擦、ねじ保持力は未検証。使用前後に爪根元の白化・割れ・永久変形を確認する。強い負荷で歯飛び・変形が起きる場合は、爪の寸法変更または金属部品方式を検討する。

## STLの生成

```sh
openscad -D 'render_part="gear"' -o motor_gear_38_oneway_gear.stl motor_gear_38_oneway.scad
openscad -D 'render_part="hub"' -o motor_gear_38_oneway_hub.stl motor_gear_38_oneway.scad
openscad -D 'render_part="cover"' -o motor_gear_38_oneway_cover.stl motor_gear_38_oneway.scad
```

## CAD検証結果

- OpenSCAD 2021.01で3部品のSTL生成に成功（`--hardwarnings`）。すべてSimpleな立体、各部品は1個の実体。
- STLの全三角形の辺を照合し、各辺がちょうど2面に属することを確認。
- 組立初期位置でハブと外側ギア・蓋の共通体積は空（意図しない重なりなし）。
- 外側ギアを固定し、ハブをCCWへ2度回した場合は3箇所で内歯と爪が接触する形状になることを確認。これはロック位置の幾何検査であり、負荷時の保持能力を保証しない。
- 弾性腕と固定部は半径25.2 mm以内。内歯の最小半径26 mmに対して0.8 mmの余裕を持ち、意図的に接触する爪先以外は全回転位相で内歯を避ける。
- `motor_gear_38_oneway_open.png`（内部）と `motor_gear_38_oneway_exploded.png`（分解）を出力。

空転中の腕のたわみ・歯への追従・トルク・160 RPMでの連続運転は未検証。

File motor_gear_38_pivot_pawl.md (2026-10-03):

# 別体爪・ピン支点式ワンウェイクラッチの形状試作

`motor_gear_38_pivot_pawl.scad` をOpenSCADで開く。既定は上の蓋とピン押さえ板を外した内部表示。

元の `motor_gear_38.scad`、一体バネ版 `motor_gear_38_oneway.scad` は変更しない。歯車・D穴・外側ギア・蓋を参照するため、これら2ファイルとBOSL2を同じ場所に残す。

## 今の試作との違い

緑色の爪は厚さ4 mmの独立部品。銀色の金属ピンを支点に回転し、赤色の独立したねじりバネで戻す。駆動時は爪のかかとがハブの受けに当たる設計で、戻しバネを駆動トルクの伝達部品にしない。ハブ上の水色の押さえ板でピンの上端を支える。

+Z（テーブル上面）から見てモーターは反時計回り、テーブルは時計回り。停止後は外側38歯ギアが反時計回りに追い越す。内歯の斜面で爪がピンの周りに反時計回りに倒れ、内側へ退避する。

**赤いバネは購入品未選定の取付スペース検討モデル。バネ定数・自由角・予圧は未確定で、現時点で実働を確認した設計ではない。** 3Dプリント用STLにはバネとピンを含めない。

## 表示方法

| 設定 | 表示 |
| --- | --- |
| `render_part="open"` | 爪とバネが見える内部（既定） |
| `show_retainer=true` | 内部表示にピン押さえ板を追加 |
| `render_part="assembly"` | 蓋と押さえ板を含む組立 |
| `render_part="exploded"` | 分解表示 |
| `pawl_lift_angle=20` | 爪を内側へ倒した状態 |
| `render_part="motion"` | 爪だけを0〜20度で往復させる表示 |
| `render_part="layout"` | 印刷部品を並べる（爪3個含む） |
| `gear / hub / pawl / retainer / cover` | 各部品の単独出力 |

`motion`ではOpenSCADの「表示→アニメーション」でFPS=20、Steps=100などを指定する。これは可動方向を見るための表示で、歯車の回転と同期した接触解析ではない。バネの可動脚は爪に追従するが、コイルの弾性変形は計算しない。

## 部品構成

| 部品 | 個数 | 備考 |
| --- | ---: | --- |
| 外側ギア / gear | 1 | 一体バネ版と同形状 |
| ハブ / hub | 1 | D穴・下側ピン支持・爪の受け |
| 爪 / pawl | 3 | すべて同形状、厚さ4 mm |
| ピン押さえ板 / retainer | 1 | ハブへ固定、上側ピン穴は盲穴 |
| 蓋 / cover | 1 | 一体バネ版と同形状、外側ギアへ固定 |
| 金属平行ピン φ3×8 mm | 3 | 下側支持穴・爪・上側支持穴を通す |
| 小型ねじりバネ | 3 | **未選定**、下記のスペースに合わせて再設計する |
| 樹脂に適したM2.5皿ねじ 長さ6 mm | 3 | ピン押さえ板用。頭径5 mm・90度の仮寸法 |
| 樹脂に適したM2.5ねじ 長さ8 mm | 3 | 外側の蓋用 |

バネ参考寸法：線径0.3 mm、コイル平均径4.5 mm（内径4.2 mm、外径4.8 mm）、約3巻。コイルは爪の上のZ=8.1〜9.25 mmの範囲。両脚端を下へ曲げてハブと爪のφ0.9 mm穴へ入れる案。φ3ピンを中心に置き、爪を時計回りへ戻す向きに予圧を与える必要がある。**この数値をそのまま購入仕様にはしないこと。実際のバネのコイル幅・脚形状・巻方向・自由角に合わせて部品を修正する。** 0.9 mmの小穴や脚溝は印刷後の仕上げが必要になる場合がある。

## 印刷・仮組立

- PETG、爪と押さえ板は底面を下にして印刷。爪の支点穴のバリを除去し、ピン上で軽く回ることを確認する。
- ハブは高さ2.2 mmから下側支持腕が張り出すため、その下面へビルドプレートからサポートを付ける。
- ピン穴の径は3.3 mmで、実物ピンに対して直径0.3 mmのすき間。プリンターに合わせて `pin_hole_d` を調整する。実物がピンの周りで固着する場合は使わない。
- 外側ギアへハブを入れ、3個の爪・ピン・バネを取り付ける。バネの固定脚はハブの溝へ、可動脚は爪の穴へ入れる。
- ハブに押さえ板を皿ねじで固定する。皿ねじ頭が押さえ板上面から出ないこと、押さえ板と爪・バネが擦らないことを確認する。
- 外側ギアへ蓋を取り付ける。ハブを固定し、外側ギアが反時計回りに空転し、時計回りでは噛むことを手で確認する。
- 外側の蓋のねじ頭は本体13 mmから突出する。モーター軸からの抜け止めは別途必要。

## 検証と制約

CAD形状の確認と実機性能の確認は別。160 RPM・10 kgf·cmのモーターを想定しているが、爪・受け・ピン支持部・D穴の許容トルク、バネの追従性、空転抵抗、PETGの摩耗や寿命は未検証。

実施したCAD検査：

- OpenSCAD 2021.01で5種類のSTLを警告なしで生成。各STLは1個の実体で、全辺が2面に属する閉じたメッシュ。
- 待機位置の爪とハブ・押さえ板・外側ギアの共通体積は空。
- ハブと外側ギア・押さえ板・蓋の共通体積は空。
- 爪の0〜20度の退避動作を0.5度刻みで断面検査し、ハブ胴体・受けとの重なりがないことを確認。
- 逆方向へ4度動かすと受けに当たることを確認。20度退避時には爪全体が半径25.8 mm以内に入り、内歯先半径26 mmより内側になることを確認。
- 内部・分解PNGを目視確認。元SCAD2ファイルのSHA-256が作業前後で一致。

これらは理想形状の幾何検査であり、印刷誤差や部品の遊び、歯と爪の動的接触、バネの弾性は含まない。

24歯の内歯を使用するため、モーター停止直後に外側ギアが160 RPMなら各爪は毎秒64回歯を越える。爪3個は同位相。バネを弱くしすぎると噛み合い遅れが生じる可能性があり、強くしすぎると空転抵抗が増える。無負荷・低速から確認する。

この版では、外側ギアとハブ間の支持はPETGの摺動面を継続して使用している。爪を別体化しても、その摺動抵抗は残る。

STLは `motor_gear_38_pivot_pawl_gear.stl` / `_hub.stl` / `_pawl.stl` / `_retainer.stl` / `_cover.stl`。爪STLを3個印刷する。

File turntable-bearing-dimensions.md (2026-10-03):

# 6インチ ターンテーブルベアリング寸法

## 概要

提供画像から読み取った、6インチ・ターンテーブルベアリングの寸法をまとめる。

- 呼称サイズ：6インチ
- 寸法単位：mm（画像中に単位表記はないが、製品サイズと数値から mm と判断）
- 図には通常位置と、一方のプレートを回転させて取付穴を露出させた状態が掲載されている

## 寸法一覧

| 対象 | 寸法項目 | 寸法 |
|---|---|---:|
| 角型 | 本体外形幅 | 156 mm |
| 共通 | 中央開口径 | φ119.5 mm |
| φ6.4穴側 | 取付穴径 | φ6.4 mm |
| φ6.4穴側 | 取付穴の中心間距離 | 136 mm |
| φ4.9穴側 | 取付穴径 | φ4.9 mm |
| φ4.9穴側 | 取付穴の中心間距離 | 120 mm |
| 回転展開時 | 最大外形幅 | 215 mm |
| 共通／側面図 | 板厚 | 0.8 mm |
| 共通／側面図 | 全厚 | 8.7 mm |

## 寸法の読み方

### 通常位置

- 正方形の本体外形は 156 × 156 mm と読み取れる。
- 中央の大きな開口径は φ119.5 mm。
- 大きい取付穴の直径は φ6.4 mm。
- φ6.4 mm の取付穴同士の中心間距離は 136 mm。

### 回転展開時

- 一方のプレートを回転させると、取付穴のある角部が上下左右へ張り出して見える。
- 左右タブ先端間の最大外形は 215 mm。
- 小さい取付穴の直径は φ4.9 mm。
- φ4.9 mm の取付穴同士の中心間距離は 120 mm。

## 使用上の注意

- 元画像は低解像度で、一部の寸法補助線と矢印の対応が不鮮明である。
- 「0.8 mm」が板厚であることは画像からの推定を含む。
- 加工用図面や部品選定に使用する場合は、現物測定またはメーカーの正式図面で寸法、公差、穴位置を確認すること。

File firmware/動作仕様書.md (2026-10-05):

# SENME Firmware 動作仕様書

作成日：2026年9月24日  
対象：`senme_controller`（ESP32コントローラー）  
根拠：現行の [Control.h](senme_controller/Control.h) と [senme_controller.ino](senme_controller/senme_controller.ino)

本書は現在のソースコードの動作を記載する。実機に書き込まれているバージョンや、実機での回転・波形を確認した結果ではない。揺れ検知送信機 `sense_sender` の動作は対象外とする。

## 1. 共通仕様

### 1.1 起動とモード切替

電源投入・リセット時は保存済み設定を読み込み、ESP-NOWモードの受信待機から開始する。モーター出力は0%、LEDは5秒周期でフェードする。START未受信なら自動運転は開始しない。前回のモードや進行位置は復元しない。

ボタンを短押しして離すと、次の順序でモードが切り替わる。

```text
シーケンス → LED Edit（編集1） → Motor Edit（編集2） → ESP-NOW → シーケンス
```

モード切替に伴うモーター停止処理中とESP-NOWの実行受付後～運転終了までは、短押しによる次のモードへの切替を受け付けない。シーケンス内の通常減速区間では短押しによる切替が可能。無効期間中の操作は予約されない。

### 1.2 LEDの表示

| 表示 | 動作 |
| --- | --- |
| フェードイン・アウト | 5秒周期で明るさ0% → 100% → 0%を繰り返す。開始から2.5秒で最大、5秒で0%。sin波に相当する滑らかな変化 |
| 開始フェードイン | モーター加速中の15秒間、明るさを0%から100%へ直線的に上げ、その後に設定周期の点滅へ切り替える |
| 設定値による点滅 | 55.55ms周期で繰り返し点灯。各周期の点灯時間はLED Editの設定値を使用。点灯中の出力は100% |

開始フェードインは1kHz PWMのデューティ比を15秒で0%から100%へ上げる。割合は制御値であり、測定した照度や人が感じる明るさの比率ではない。15秒の境界で点滅へ切り替え、100%で保持する時間は設けない。

点灯時間0msの場合、「点滅」区間でも消灯する。55.55msの場合は100%連続点灯になる。加速中の開始フェードインと待機中のフェードは、この点灯時間設定の影響を受けない。

### 1.3 モーター出力

本書の「最大値」はMotor Editで設定した最大PWM出力率を指す。100%固定ではない。実回転数を測定・制御する機能はない。

| 項目 | 仕様 |
| --- | --- |
| 開始 | 15秒かけて55%から設定最大値まで直線的に上昇 |
| 通常停止 | 15秒かけて停止開始時の出力から55%まで直線的に下降し、15秒終了時に即0% |
| 55%の意味 | PWM出力率の絶対値55%。設定最大値の55%ではない |
| 停止開始時の出力が0%超～55%以下 | 出力を上げず、現在の出力を15秒維持した後、即0% |
| 既に出力0%でモード切替 | 減速のための15秒待機は不要 |

開始時はPWM出力を55%にし、15秒かけて設定最大値へ上げます。設定最大値が55%以下の場合は、その設定値を開始時から維持します（0%設定なら出力しません）。この開始処理はシーケンス・Motor Edit・ESP-NOWに共通です。

シーケンス・ESP-NOWは最大値が0%でも所定の時間配分とLED表示で進行する。
モード切替で途中停止する場合は、最大値に上げ直さず、直前に適用した実際のPWM出力から停止処理を開始する。
出力0%はモーターへの停止指令であり、軸の停止検知やブレーキ制御は行わない。

## 2. シーケンスモード

110秒を1周期として自動的に繰り返す。ESP-NOWからこのモードへ切り替えた際は0秒から開始する。

| 経過時間 | 継続時間 | モーター | LED |
| --- | --- | --- | --- |
| 0秒以上～20秒未満 | 20秒 | 0% | フェードイン・アウトを4周期 |
| 20秒以上～35秒未満 | 15秒 | 55% → 設定最大値へ加速 | 0%→100%の開始フェードイン |
| 35秒以上～95秒未満 | 60秒 | 設定最大値を維持 | 設定値による点滅 |
| 95秒以上～110秒未満 | 15秒 | 設定最大値 → 55%へ減速 | 設定値による点滅を継続 |
| 110秒 | 瞬時の切替 | 即0% | 明るさ0%からフェードを再開し、次の周期へ |

点滅は設定最大値に達する35秒時点で開始する。一定出力での点滅60秒に減速中の点滅15秒が加わるため、点滅区間全体は75秒となる。

短押しするとLED Editへ切り替わる。モーターが動いている場合は、LEDを設定値による点滅に切り替え、現在出力から15秒の停止処理を行う。停止処理中の追加短押しは無効。シーケンスの通常減速中に短押しした場合も、切替時点から改めて15秒かけて停止するため、元の停止予定より遅くなる。この延長は許容する。ロータリー操作・長押し保存・START受信は、このシーケンスモード中は無効。

## 3. LED Edit（編集1）

LEDの点滅周期内の点灯時間を調整するモード。通常はモーター出力0%だが、シーケンスから切り替えた直後はモーターの停止処理が最大15秒間継続する。

| 操作・項目 | 仕様 |
| --- | --- |
| LED | 現在の点灯時間設定で点滅 |
| 時計回り1クリック | 点灯時間を0.5ms増加 |
| 反時計回り1クリック | 点灯時間を0.5ms減少 |
| 設定範囲 | 0～55.55ms。範囲外へ回しても端の値で止まる |
| 初期値 | 5.0ms点灯／55.55ms周期 |
| 3秒長押し | LEDの点灯時間のみ保存 |
| 短押し | Motor Editへ切替。ただしモーター停止処理中は無効 |
| START | 破棄 |

点滅周期55.55msは固定で、ロータリーで変更されるのは点灯時間のみ。例えば設定5.0msなら、5.0ms点灯＋50.55ms消灯となる。
モーター停止処理中でも、LEDの調整と保存は可能。

点灯時間は0.5ms刻みで55.5msまで調整でき、その次が連続点灯の55.55msです。旧設定の56ms連続点灯は読み込み時に55.55msへ移行します。

## 4. Motor Edit（編集2）

モーターの最大PWM出力率を調整するモード。

| 入ってからの時間 | モーター | LED |
| --- | --- | --- |
| 0秒以上～15秒未満 | 55%から現在の設定最大値に向けて加速 | 0%→100%の開始フェードイン |
| 15秒以降 | 現在の設定最大値を出力 | 設定値による点滅 |

| 操作・項目 | 仕様 |
| --- | --- |
| 時計回り1クリック | 最大値を1パーセントポイント増加 |
| 反時計回り1クリック | 最大値を1パーセントポイント減少 |
| 設定範囲 | 0～100%。範囲外へ回しても端の値で止まる |
| 初期値 | 55% |
| 3秒長押し | モーター最大値のみ保存 |
| 短押し | ESP-NOWへ切替し、モーター停止処理を開始 |
| START | 破棄 |

加速中に設定を変更した場合、`開始値 + (現在の設定最大値 − 開始値) × 入ってからの経過時間 ÷ 15秒`（開始値は55%と現在の設定最大値の小さい方） を出力する。15秒の計測をやり直すことはない。15秒経過後の設定変更は出力へ直接反映され、変更のたびに15秒の加減速を行うわけではない。

退出時は、LEDを設定値による点滅にし、現在のモーター出力から15秒で55%へ減速して即0%にする。加速途中の退出も同様。停止中は既にESP-NOWモードに移っているため、ロータリー操作・長押し保存は無効であり、STARTと追加短押しも受け付けない。停止完了後にLEDのフェードとSTART受付を開始する。

## 5. ESP-NOWモード

### 5.1 待機と運転

電源投入・リセット時は初期化完了後、停止処理の待ち時間なしで待機に入る。Motor Editから移った際は、前節の停止処理を終えてから待機に入る。待機中はモーター0%、LEDは明るさ0%から5秒周期のフェードイン・アウトを続ける。待機に時間制限はない。

有効なSTARTを1件受け付けると、その時点で後続のSTARTを受け付けなくなる。次のメインループ処理で、モーター出力を0%に保ったままLEDを1秒間に6回点滅（100%点灯と消灯を約83msずつ交互）させる。通知中の追加START・短押しは無効。通知終了後に60秒の運転を開始する（通知を含め約61秒）。

| 運転開始からの経過時間 | 継続時間 | モーター | LED | 後続START |
| --- | --- | --- | --- | --- |
| 0秒以上～15秒未満 | 15秒 | 55% → 設定最大値へ加速 | 0%→100%の開始フェードイン | 破棄 |
| 15秒以上～45秒未満 | 30秒 | 設定最大値を維持 | 設定値による点滅 | 破棄 |
| 45秒以上～60秒未満 | 15秒 | 設定最大値 → 55%へ減速 | 設定値による点滅を継続 | 破棄 |
| 60秒・停止完了〜停止後3秒未満 | 3秒 | 0% | 明るさ0%からフェードを再開 | 破棄 |
| 停止後3秒以降 | 次のSTARTまで | 0% | フェードを継続 | 受付再開 |

最大値維持は30秒。減速中も点滅するため、点滅区間全体は45秒。加速・維持・減速を合わせた運転時間は60秒。

メイン処理でモーターPWMを0%にし、LEDをフェードへ切り替えた時点から3秒間、STARTを破棄する。3秒経過後のメインループで受付を再開し、新しいSTARTが届けば次の運転を開始できる。3秒間のメッセージは保存・予約しない。LEDのフェードは受付再開時にリセットせず継続する。起動時とMotor Editからの移行時には、この3秒待機を設けない。停止後の3秒間も短押しによるシーケンスへの切替は可能。

運転中に破棄したSTARTは保存・予約・再実行せず、運転時間の延長もしない。停止後3秒の受付抑止が終わってから届く再送は、新しいSTARTとして扱う。

### 5.2 操作と通信

| 項目 | 仕様 |
| --- | --- |
| 待機中の短押し | シーケンスへ切替し、20秒のフェード区間から再開 |
| START受付後・運転中・Motor Edit退出時の停止中の短押し | 無効 |
| ロータリー操作／長押し保存 | 無効 |
| 運転設定 | LED EditとMotor Editの現在値を使用。未保存変更も使用 |
| 有効な本文 | ASCII `START` の5バイト、または末尾NULを含む6バイト |
| 無効な本文 | 小文字、改行付き、JSON、その他の長さ・内容 |
| Wi-Fiチャンネル | 1 |
| 送信元制限 | 送信元MACによる制限なし。暗号化なし |
| 実行受付の応答 | アプリケーション側のACKなし |

「受信不可」は、無線を停止する意味ではなく、アプリケーションでメッセージを破棄することを指す。ESP-NOW待機状態以外では本文を解析せず破棄する。送信成功だけでは、運転開始が受け付けられたとは判断できない。

## 6. 設定の保存

設定変更はすぐに有効になり、保存前でも別モードで使用される。再起動後も保持するには、対象の編集モードで3秒長押しする。

| 設定 | 保存するモード | 保存値がない場合 |
| --- | --- | --- |
| LED点灯時間 | LED Edit | 5.0ms |
| モーター最大出力 | Motor Edit | 55% |

長押し1回につき保存は1回のみ。長押し後にボタンを離してもモードは切り替わらない。他方の設定は同時保存されない。シリアルログに `SAVED` または `SAVE FAILED` を表示する。保存成功時のみ、LEDを明るさ100%で約3Hz、1秒間に3回点滅させる（約167ms点灯／約167ms消灯）。この間は通常のLED表示より確認点滅を優先し、1秒後に現在のモードの表示へ戻す。モーター制御やモードの時間計測は継続する。

保存領域を利用できない場合は初期値で開始し、RAM上での変更は可能だが保存はできない。不正な保存値は、その項目の初期値に戻す。

## 7. 実装上の時間精度と例外

- 各時間はFirmwareの制御時間。メインループの処理時間やOSのスケジューリングによる遅延がある。
- LEDの調光（1kHz）と点滅（55.55ms周期）の切替には、約55.55msの消灯が入る。表の切替時刻は論理上の時刻であり、実際の波形にはこの切替時間が含まれる。
- モーターPWMは20kHz・10bit。出力率には量子化がある。55%で一定時間保持する段階はなく、15秒の減速が終わると0%へ切り替える。
- 初期最大値55%のままでは、開始時から55%を維持し、停止区間も55%を15秒維持した後に0%となる。55%より上から減速する動作を確認するには、最大値を55%より大きく設定する。
- LED・モーター制御APIなどの異常時はSTARTを無効化し、最後に正常適用したPWM出力から15秒で55%まで下げた後、0%を指令する。55%以下は15秒維持し、既に0%またはモーター未初期化なら直ちにOFFを指令する。停止処理後にLED消灯を試み、リセット待ちに入る。停止中のAPI失敗で異常処理を再帰呼び出ししない。モーターAPI失敗時は減速を保証できない旨をログに残し、最終0%指令が失敗した場合は1秒ごとに0%を再試行する。API復旧後も運転は再開しない。電源断・CPU停止時の減速は保証しない。

## 8. 検証状況

直近の変更時に、[制御ロジックテスト](tests/control_test.cpp)とESP32向けコンパイルが成功している。テストはモードごとの時間境界、加速中のLED 0%→100%、設定範囲、停止処理、START破棄と停止後3秒の受信抑止と再受付、ボタン操作、時計の桁あふれを対象とする。

ユーザーの変更依頼（2026年10月4日）により、現在の加速始点・減速終点は55%。55%での実機確認は未実施。
最新Firmware全体の実機検証状況、LED波形、電源ノイズ、保存・復元、ESP-NOW実通信の検証結果は本書では未確認。仕様書の更新によるFirmwareの動作変更はない。

## 9. レビューで確認済みの判断

以下はユーザー確認済みの仕様として維持する。

| 項目 | 判断・理由 |
| --- | --- |
| 加速の始点・減速の終点55% | ユーザーの変更依頼に基づく。減速は15秒で55%へ下げ、その後即0%とする。実機確認は未実施 |
| Motor Editの変更を即時反映 | ロータリーによる1パーセントポイント刻みの調整を前提としており、変更のたびの15秒加減速は不要 |
| 減速中のモード切替による停止時間の延長 | 切替時点から15秒の停止処理を再開する現行動作を許容する |

上記のレビュー指摘は、許容する仕様として解消済み。制御コードの修正は行わない。

点滅の点灯区間は100%出力とし、RMTキャリアは無効にする。点滅周期55.55msと設定点灯時間は維持する。

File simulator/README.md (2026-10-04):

# Senme Simulator

球体リソファンの3Dプレビュー・形状調整・STL出力用アプリです。旧experimentalを改名し、必要なソース・設定・テストをこのフォルダ内にまとめています。このフォルダだけを別の場所へコピーしても使用できます。

## 起動

Node.js 22.12以上とnpmが必要です。このフォルダで実行してください。

```sh
npm ci
npm run dev
```

http://127.0.0.1:5174/ を開いてください。以前の `/experimental/` ではなく、ルートURLでアプリが起動します。
インストール済みなら `npm run dev` だけで起動できます。停止は `Ctrl+C` です。
ポートが使用中なら既存サーバーを停止するか、`npm run dev -- --port 5175` を使用してください。
HTMLの直接オープンではなく、Vite経由で使用します。

## ビルドと確認

```sh
npm run build
npm run preview -- --host 127.0.0.1
npm test
npm run test:typecheck
npm run lint
```

ビルド結果はこのフォルダ内の `dist/` に出力されます。previewのURLはターミナルに表示されます。

## データと構成

- `index.html`・`main.ts`・`styles.css`: 画面と起動処理
- ルートのその他の `.ts`: 形状生成・保存・バックアップ
- `src/`: 形状計算などの共通コード
- `images/`: テクスチャ設定から選択できるサンプル画像
- `tests/`: 形状生成・保存・バックアップのテスト

設定と登録画像はブラウザ内に保存されます。従来の保存キー・ZIP形式は互換性のため維持しています。同じブラウザ・ホスト名・ポートで開けば既存データを引き継ぎます。ホスト名・ポート・ブラウザを変更する場合は、旧画面のExportでZIPを保存し、新しい画面のImportで取り込んでください。

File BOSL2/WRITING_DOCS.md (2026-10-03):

Documenting OpenSCAD Code
-------------------------------------------------

Documentation comment blocks are all based around a single simple syntax:

    // Block Name(Metadata): TitleText
    //   Body line 1
    //   Body line 2
    //   Body line 3

- The Block Name is one or two words, both starting with a capital letter.
- The Metadata is in parentheses.  It is optional, and can contain fairly arbitrary text, as long as it doesn't include newlines or parentheses. If the Metadata part is not given, the parentheses are optional.
- A colon `:` will always follow after the Block Name and optional Metadata.
- The TitleText will be preceded by a space ` `, and can contain arbitrary text, as long as it contains no newlines.  The TitleText part is also optional for some header blocks.
- The body will contain zero or more lines of text indented by three spaces after the comment markers.  Each line can contain arbitrary text.

So, for example, a Figure block to show a 640x480 animated GIF of a spinning shape may look like:

    // Figure(Spin,Size=640x480,VPD=444): A Cube and Cylinder.
    //   cube(80, center=true);
    //   cylinder(h=100,d=60,center=true);

Various block types don't need all of those parts, so they may look simpler:

    // Topics: Mask, Cylindrical, Attachable

Or:

    // Description:
    //   This is a description.
    //   It can be multiple lines in length.

Or:

    // Usage: Typical Usage
    //   x = foo(a, b, c);
    //   x = foo([a, b, c, ...]);

Comments blocks that don't start with a known block header are ignored and not added to output documentation.  This lets you have normal comments in your code that are not used for documentation.  If you must start a comment block with one of the known headers, then adding a single extra `/` or space after the comment marker, will make it be treated as a regular comment:

    /// File: Foobar.scad

Block Headers
=======================

File/LibFile Blocks
-------------------

All files must have either a `// File:` block or a `// LibFile:` block at the start.  This is the place to put in the canonical filename, and a description of what the file is for.  These blocks can be used interchangably, but you can only have one per file.  `// File:` or `// LibFile:` blocks can be followed by a multiple line body that are added as markdown text after the header:

    // LibFile: foo.scad
    //   You can have several lines of markdown formatted text here.
    //   You just need to make sure that each line is indented, with
    //   at least three spaces after the comment marker.  You can
    //   denote a paragraph break with a comment line with three
    //   trailing spaces, or just a period.
    //   .
    //   You can have links in this text to functions, modules, or
    //   constants in other files by putting the name in double-
    //   braces like {{cyl()}} or {{lerp()}} or {{DOWN}}.  If you want to
    //   link to another file, or section in another file you can use
    //   a manual markdown link like [Section: Cuboids](shapes.scad#section-cuboids).
    //   The end of the block is denoted by a line without a comment.

Which outputs Markdown code that renders like:

> ## LibFile: foo.scad
> You can have several lines of markdown formatted text here.
> You just need to make sure that each line is indented, with
> at least three spaces after the comment marker.  You can
> denote a paragraph break with a comment line with three
> trailing spaces, or just a period.
> 
> You can have links in this text to functions, modules, or
> constants in other files by putting the name in double-
> braces like [cyl()](shapes.scad#functionmodule-cyl) or [lerp()](math.scad#function-lerp) or [DOWN](constants.scad-down).  If you want to
> link to another file, or section in another file you can use
> a manual markdown link like [Section: Cuboids](shapes.scad#section-cuboids).
> The end of the block is denoted by a line without a comment.

You can use `// File:` instead of `// LibFile:`, if it seems more apropriate for your particular context:

    // File: Foobar.scad
    //   This file contains a collection of metasyntactical nonsense.

Which outputs Markdown code that renders like:

> # File: Foobar.scad
> This file contains a collection of metasyntactical nonsense.

FileGroup Block
---------------

You can specify what group of files this .scad file is a part of with the `// FileGroup:` block:

    // FileGroup: Advanced Modeling

This affects the ordering of files in Table of Contents and CheatSheet files.  This doesn't generate any output text otherwise.

FileSummary Block
-----------------

You can give a short summary of the contents of this .scad file with the `// FileSummary:` block:

    // FileSummary: Various modules to generate Foobar objects.

This summary is used when summarizing this .scad file in the Table of Contents file.  This will result in a line in the Table of Contents that renders like:

> - [Foobar.scad](Foobar.scad): Various modules to generate Foobar objects.

FileFootnotes Block
-------------------

You can specify footnotes that are appended to this .scad file's name wherever the list of files is shown, such as in the Table of Contents.  You can do this with the `// FileFootnotes:` block.  The syntax looks like:

    // FileFootnotes: 1=First Footnote; 2=Second Footnote

Multiple footnotes are separated by semicolons (`;`).  Within each footnote, you specify the footnote symbol and the footnote text separated by an equals sign (`=`).  The footnote symbol may be more than one character, like this:

    // FileFootnotes: STD=Included in std.scad

This will result in footnote markers that render like:

> - Foobar.scad<sup id="fn_std">[STD](#footnote-std "Included in std.scad")</sup>

Includes Block
--------------

To declare what code the user needs to add to their code to include or use this library file, you can use the `// Includes:` block.  You should put this right after the `// File:` or `// LibFile:` block. This code block will also be prepended to all Example and Figure code blocks before they are evaluated:

    // Includes:
    //   include <BOSL2/std.scad>
    //   include <BOSL2/gears.scad>

Which outputs Markdown code that renders like:

> **Includes:**
>
> To use, add the following lines to the beginning of your file:
>
> ```openscad
>  include <BOSL2/std.scad>
>  include <BOSL2/gears.scad>
> ```

CommonCode Block
----------------

If you have a block of code you plan to use throughout the file's Figure or Example blocks, and you don't actually want it displayed, you can use a `// CommonCode:` block like thus:

    // CommonCode:
    //   module text3d(text, h=0.01, size=3) {
    //       linear_extrude(height=h, convexity=10) {
    //           text(text=text, size=size, valign="center", halign="center");
    //       }
    //   }

This doesn't have immediately visible markdown output, but you *can* use that code in later examples:

    // Example:
    //   text3d("Foobar");

Section Block
-------------

Section blocks take a title, and an optional body that will be shown as the description of the Section.  If a body line if just a `.` (dot, period), then that line is treated as a blank line in the output:

    // Section: Foobar
    //   You can have several lines of markdown formatted text here.
    //   You just need to make sure that each line is indented, with
    //   at least three spaces after the comment marker.  You can
    //   denote a paragraph break with a comment line with three
    //   trailing spaces, or just a period.
    //   .
    //   You can have links in this text to functions, modules, or
    //   constants in other files by putting the name in double-
    //   braces like {{cyl()}} or {{lerp()}} or {{DOWN}}.  If you want to
    //   link to another file, or section in another file you can use
    //   a manual markdown link like [Section: Cuboids](shapes.scad#section-cuboids).
    //   .
    //   The end of the block is denoted by a line without a comment.
    //   or a line that is unindented after the comment.

Which outputs Markdown code that renders like:

> ## Section: Foobar
> You can have several lines of markdown formatted text here.
> You just need to make sure that each line is indented, with
> at least three spaces after the comment marker.  You can
> denote a paragraph break with a comment line with three
> trailing spaces, or just a period.
>
> You can have links in this text to functions, modules, or
> constants in other files by putting the name in double-
> braces like [cyl()](shapes.scad#functionmodule-cyl) or [lerp()](math.scad#function-lerp) or [DOWN](constants.scad-down).  If you want to
> link to another file, or section in another file you can use
> a manual markdown link like [Section: Cuboids](shapes.scad#section-cuboids).
>
> The end of the block is denoted by a line without a comment.
> or a line that is unindented after the comment.

Sections can also include Figures; images generated from code that is not shown in a code block.

Subsection Block
----------------

Subsection blocks take a title, and an optional body that will be shown as the description of the Subsection.  A Subsection must be within a declared Section.  If a body line is just a `.` (dot, period), then that line is treated as a blank line in the output:

    // Subsection: Foobar
    //   You can have several lines of markdown formatted text here.
    //   You just need to make sure that each line is indented, with
    //   at least three spaces after the comment marker.  You can
    //   denote a paragraph break with a comment line with three
    //   trailing spaces, or just a period.
    //   .
    //   You can have links in this text to functions, modules, or
    //   constants in other files by putting the name in double-
    //   braces like {{cyl()}} or {{lerp()}} or {{DOWN}}.  If you want to
    //   link to another file, or section in another file you can use
    //   a manual markdown link like [Subsection: Foo](shapes.scad#subsection-foo).
    //   .
    //   The end of the block is denoted by a line without a comment.
    //   or a line that is unindented after the comment.

Which outputs Markdown code that renders like:

> ## Subsection: Foobar
> You can have several lines of markdown formatted text here.
> You just need to make sure that each line is indented, with
> at least three spaces after the comment marker.  You can
> denote a paragraph break with a comment line with three
> trailing spaces, or just a period.
>
> You can have links in this text to functions, modules, or
> constants in other files by putting the name in double-
> braces like [cyl()](shapes.scad#functionmodule-cyl) or [lerp()](math.scad#function-lerp) or [DOWN](constants.scad-down).  If you want to
> link to another file, or section in another file you can use
> a manual markdown link like [Subsection: Foo](shapes.scad#subsection-foo).
>
> The end of the block is denoted by a line without a comment.
> or a line that is unindented after the comment.

Subsections can also include Figures; images generated from code that is not shown in a code block.

Item Blocks
-----------

Item blocks headers come in four varieties: `Constant`, `Function`, `Module`, and `Function&Module`.

The `Constant` header is used to document a code constant.  It should have a Description sub-block, and Example sub-blocks are recommended:

    // Constant: PHI
    // Description: The golden ratio phi.
    PHI = (1+sqrt(5))/2;

Which outputs Markdown code that renders like:

> ### Constant: PHI
> **Description:**
> The golden ration phi.

The `Module` header is used to document a module.  It should have a Description sub-block. It is recommended to also have Usage, Arguments, and Example/Examples sub-blocks.  The Usage sub-block body lines are also used when constructing the Cheat Sheet index file:

    // Module: cross()
    // Usage:
    //   cross(size);
    // Description:
    //   Creates a 2D cross/plus shape.
    // Arguments:
    //   size = The scalar size of the cross.
    // Example(2D):
    //   cross(size=100);
    module cross(size=1) {
        square([size, size/3], center=true);
        square([size/3, size], center=true);
    }

Which outputs Markdown code that renders like:

> ### Module: cross()
> **Usage:**
> - cross(size);
> 
> **Description:**
> Creates a 2D cross/plus shape.
> 
> **Arguments:**
> Positional Arg | What it does
> -------------------- | -------------------
> size                   | The scalar size of the cross.
> 
> **Example:**
> ```openscad
> cross(size=100);
> ```
> GENERATED IMAGE GOES HERE

The `Function` header is used to document a function.  It should have a Description sub-block. It is recommended to also have Usage, Arguments, and Example/Examples sub-blocks.  By default, Examples will not generate images for function blocks.  Usage sub-block body lines are also used when constructing the Cheat Sheet index file:

    // Function: vector_angle()
    // Usage:
    //   ang = vector_angle(v1, v2);
    // Description:
    //   Calculates the angle between two vectors in degrees.
    // Arguments:
    //   v1 = The first vector.
    //   v2 = The second vector.
    // Example:
    //   v1 = [1,1,0];
    //   v2 = [1,0,0];
    //   angle = vector_angle(v1, v2);
    //   // Returns: 45
    function vector_angle(v1,v2) =
    acos(max(-1,min(1,(vecs[0]*vecs[1])/(norm0*norm1))));

Which outputs Markdown code that renders like:

> ### Function: vector_angle()
> **Usage:**
> - ang = vector_angle(v1, v2);
> 
> **Description:**
> Calculates the angle between two vectors in degrees.
> 
> **Arguments:**
> Positional Arg | What it does
> -------------------- | -------------------
> `v1`                | The first vector.
> `v2`                | The second vector.
> 
> **Example:**
> ```openscad
> v1 = [1,1,0];
> v2 = [1,0,0];
> angle = vector_angle(v1, v2);
> // Returns: 45
> ```

The `Function&Module` header is used to document a function which has a related module of the same name.  It should have a Description sub-block.  It is recommended to also have Usage, Arguments, and Example/Examples sub-blocks. You should have Usage blocks for both calling as a function, and calling as a module.  Usage sub-block body lines are also used in constructing the Cheat Sheet index file:

    // Function&Module: oval()
    // Topics: 2D Shapes, Geometry
    // Usage: As a Module
    //   oval(rx,ry);
    // Usage: As a Function
    //   path = oval(rx,ry);
    // Description:
    //   When called as a function, returns the perimeter path of the oval.
    //   When called as a module, creates a 2D oval shape.
    // Arguments:
    //   rx = X axis radius.
    //   ry = Y axis radius.
    // Example(2D): Called as a Function
    //   path = oval(100,60);
    //   polygon(path);
    // Example(2D): Called as a Module
    //   oval(80,60);
    module oval(rx,ry) {
        polygon(oval(rx,ry));
    }
    function oval(rx,ry) =
        [for (a=[360:-360/$fn:0.0001]) [rx*cos(a),ry*sin(a)];

Which outputs Markdown code that renders like:

> ### Function&Module: oval()
> **Topics:** 2D Shapes, Geometry
>
> **Usage:** As a Module
>
> - oval(rx,ry);
>
> **Usage:** As a Function
>
> - path = oval(rx,ry);
>
> **Description:**
> When called as a function, returns the perimeter path of the oval.
> When called as a module, creates a 2D oval shape.
>
> **Arguments:**
> Positional Arg | What it does
> -------------------- | -------------------
> rx | X axis radius.
> ry | Y axis radius.
>
> **Example:** Called as a Function
>
> ```openscad
> path = oval(100,60);
> polygon(path);
> ```
> GENERATED IMAGE SHOWN HERE
>
> **Example:** Called as a Module
>
> ```openscad
> oval(80,60);
> ```
> GENERATED IMAGE SHOWN HERE

These Type blocks can have a number of sub-blocks.  Most sub-blocks are optional,  The available standard sub-blocks are:

- `// Aliases: alternatename(), anothername()`
- `// Status: DEPRECATED`
- `// Topics: Comma, Delimited, Topic, List`
- `// Usage:`
- `// Description:`
- `// Figure:` or `// Figures`
- `// Continues:`
- `// Arguments:`
- `// See Also: otherfunc(), othermod(), OTHERCONST`
- `// Example:` or `// Examples:`

Aliases Block
-------------

The Aliases block is used to give alternate names for a function, module, or
constant.  This is reflected in the indexes generated.  It looks like:

    // Aliases: secondname(), thirdname()

Which outputs Markdown code that renders like:

> **Aliases:** secondname(), thirdname()

Status Block
------------

The Status block is used to mark a function, module, or constant as deprecated:

    // Status: DEPRECATED, use foo() instead

Which outputs Markdown code that renders like:

> **Status:** DEPRECATED, use foo() instead

Topics Block
------------

The Topics block can associate various topics with the current function or module.  This can be used to make an index of Topics:

    // Topics: 2D Shapes, Geometry, Masks

Which outputs Markdown code that renders like:

> **Topics:** 2D Shapes, Geometry, Masks

Usage Block
-----------

The Usage block describes the various ways that the current function or module can be called, with the names of the arguments.  By convention, the first few arguments that can be called positionally just have their name shown.  The remaining arguments that should be passed by name, will have the name followed by an `=` (equal sign).  Arguments that are optional in the given Usage context are shown in `[` and `]` angle brackets.  Usage sub-block body lines are also used when constructing the Cheat Sheet index file:

    // Usage: As a Module
    //   oval(rx, ry, <spin=>);
    // Usage: As a Function
    //   path = oval(rx, ry, <spin=>);

Which outputs Markdown code that renders like:

> **Usage:** As a Module
> - oval(rx, ry, <spin=>);
> 
> **Usage:** As a Function
> 
> - path = oval(rx, ry, <spin=>);

Description Block
-----------------
The Description block just describes the currect function, module, or constant:

    // Descripton: This is the description for this function or module.
    //   It can be multiple lines long.  Markdown syntax code will be used
    //   verbatim in the output markdown file, with the exception of `_`,
    //   which will traslate to `\_`, so that underscores in function/module
    //   names don't get butchered.  A line with just a period (`.`) will be
    //   treated as a blank line.
    //   .
    //   You can have links in this text to functions, modules, or
    //   constants in other files by putting the name in double-
    //   braces like {{cyl()}} or {{lerp()}} or {{DOWN}}.  If you want to
    //   link to another file, or section in another file you can use
    //   a manual markdown link like [Section: Cuboids](shapes.scad#section-cuboids).

Which outputs Markdown code that renders like:

> **Description:**
> It can be multiple lines long.  Markdown syntax code will be used
> verbatim in the output markdown file, with the exception of `_`,
> which will traslate to `\_`, so that underscores in function/module
> names don't get butchered.  A line with just a period (`.`) will be
> treated as a blank line.
> 
> You can have links in this text to functions, modules, or
> constants in other files by putting the name in double-
> braces like [cyl()](shapes.scad#functionmodule-cyl) or [lerp()](math.scad#function-lerp) or [DOWN](constants.scad-down).  If you want to
> link to another file, or section in another file you can use
> a manual markdown link like [Section: Cuboids](shapes.scad#section-cuboids).

Continues Block
---------------
The Continues block can be used to continue the body text of a previous block that has been interrupted by a Figure:

    // Descripton: This is the description for this function or module.  It can be
    //   many lines long.  If you need to show an image in the middle of this text,
    //   you can use a Figure, like this:
    // Figure(2D): A circle with a square cutout.
    //   difference() {
    //       circle(d=100);
    //       square(100/sqrt(2), center=true);
    //   }
    // Continues: You can continue the description text here.  It can also be
    //   multiple lines long.  This continuation will not print a header.

Which outputs Markdown code that renders like:

> **Descripton:**
> This is the description for this function or module.  It can be
> many lines long.  If you need to show an image in the middle of this text,
> you can use a Figure, like this:
>
> **Figure 1:** A circle with a square cutout.
> GENERATED IMAGE SHOWN HERE
>
> You can continue the description text here.  It can also be
> multiple lines long.  This continuation will not print a header.
>

Arguments Block
---------------
The Arguments block creates a table that describes the positional arguments for a function or module, and optionally a second table that describes named arguments:

    // Arguments:
    //   v1 = This supplies the first vector.
    //   v2 = This supplies the second vector.
    //   ---
    //   fast = Use fast, but less comprehensive calculation method.
    //   bar = Takes an optional `bar` struct.  See {{bar()}}.
    //   dflt = Default value.

Which outputs Markdown code that renders like:

> **Arguments:**
> Positional Arg | What it Does
> -------------- | ---------------------------------
> `v1`           | This supplies the first vector. 
> `v2`           | The supplies the second vector. 
>  
> Named Arg      | What it Does
> -------------- | ---------------------------------
> `fast`         | If true, use fast, but less accurate calculation method. 
> `bar`          | Takes an optional `bar` struct.  See [bar()](foobar.scad#function-bar).
> `dflt`         | Default value.

See Also Block
--------------

The See Also block is used to give links to related functions, modules, or
constants.  It looks like:

    // See Also: relatedfunc(), similarmodule()

Which outputs Markdown code that renders like:

> **See Also:** [relatedfunc()](otherfile.scad#relatedfunc), [similarmodule()](otherfile.scad#similarmodule)

Figure Block
--------------

A Figure block generates and shows an image from a script in the multi-line body, by running it in OpenSCAD.  A Figures block (plural) does the same, but treats each line of the body as a separate Figure block:

    // Figure: Figure description
    //   cylinder(h=100, d1=75, d2=50);
    //   up(100) cylinder(h=100, d1=50, d2=75);
    // Figure(Spin,VPD=444): Animated figure that spins to show all faces.
    //   cube([10,100,50], center=true);
    //   cube([100,10,30], center=true);
    // Figures:
    //   cube(100);
    //   cylinder(h=100,d=50);
    //   sphere(d=100);

Which outputs Markdown code that renders like:

> **Figure 1:** Figure description
> GENERATED IMAGE SHOWN HERE
> 
> **Figure 2:** Animated figure that spins to show all faces.
> GENERATED IMAGE SHOWN HERE
> 
> **Figure 3:**
> GENERATED IMAGE OF CUBE SHOWN HERE
> 
> **Figure 4:**
> GENERATED IMAGE OF CYLINDER SHOWN HERE
> 
> **Figure 5:**
> GENERATED IMAGE OF SPHERE SHOWN HERE

The metadata of the Figure block can contain various directives to alter how
the image will be generated.  These can be comma separated to give multiple
metadata directives:

- `NORENDER`: Don't generate an image for this example, but show the example text.
- `Hide`: Generate, but don't show script or image.  This can be used to generate images to be manually displayed in markdown text blocks.
- `2D`: Orient camera in a top-down view for showing 2D objects.
- `3D`: Orient camera in an oblique view for showing 3D objects.
- `VPD=440`: Force viewpoint distance `$vpd` to 440.
- `VPT=[10,20,30]` Force the viewpoint translation `$vpt` to `[10,20,30]`.
- `VPR=[55,0,600]` Force the viewpoint rotation `$vpr` to `[55,0,60]`.
- `Spin`: Animate camera orbit around the `[0,1,1]` axis to display all sides of an object.
- `FlatSpin`: Animate camera orbit around the Z axis, above the XY plane.
- `Anim`: Make an animation where `$t` varies from `0.0` to almost `1.0`.
- `Frames=36`: Number of animation frames to make.
- `FrameMS=250`: Sets the number of milliseconds per frame for spins and animation.
- `FPS=8`: Sets the number of frames per second for spins and animation.
- `Small`: Make the image small sized.
- `Med`: Make the image medium sized.
- `Big`: Make the image big sized.
- `Huge`: Make the image huge sized.
- `Size=880x640`: Make the image 880 by 640 pixels in size.
- `ThrownTogether`: Render in Thrown Together view mode instead of Preview mode.
- `Render`: Force full rendering from OpenSCAD, instead of the normal Preview mode.
- `Edges`: Highlight face edges.
- `NoAxes`: Hides the axes and scales.
- `NoScales`: Hides the scale numbers along the axes.
- `ScriptUnder`: Display script text under image, rather than beside it.

Example Block
-------------

An Example block shows a script, and possibly shows an image generated from it.
The script is in the multi-line body.  The `Examples` (plural) block does
the same, but it treats eash body line as a separate Example bloc to show.
Any images, if generated, will be created by running it in OpenSCAD:

    // Example: Example description
    //   cylinder(h=100, d1=75, d2=50);
    //   up(100) cylinder(h=100, d1=50, d2=75);
    // Example(Spin,VPD=444): Animated shape that spins to show all faces.
    //   cube([10,100,50], center=true);
    //   cube([100,10,30], center=true);
    // Examples:
    //   cube(100);
    //   cylinder(h=100,d=50);
    //   sphere(d=100);

Which outputs Markdown code that renders like:

> **Example 1:** Example description
> ```openscad
> cylinder(h=100, d1=75, d2=50);
> up(100) cylinder(h=100, d1=50, d2=75);
> ```
> GENERATED IMAGE SHOWN HERE
> 
> **Example 2:** Animated shape that spins to show all faces.
> ```openscad
> cube([10,100,50], center=true);
> cube([100,10,30], center=true);
> ```
> GENERATED IMAGE SHOWN HERE
> 
> **Example 3:**
> ```openscad
> cube(100);
> ```
> GENERATED IMAGE OF CUBE SHOWN HERE
> 
> **Example 4:**
> ```openscad
> cylinder(h=100,d=50);
> ```
> GENERATED IMAGE OF CYLINDER SHOWN HERE
> 
> **Example 5:**
> ```openscad
> sphere(d=100);
> ```
> GENERATED IMAGE OF SPHERE SHOWN HERE

The metadata of the Example block can contain various directives to alter how
the image will be generated.  These can be comma separated to give multiple
metadata directives:

- `NORENDER`: Don't generate an image for this example, but show the example text.
- `Hide`: Generate, but don't show script or image.  This can be used to generate images to be manually displayed in markdown text blocks.
- `2D`: Orient camera in a top-down view for showing 2D objects.
- `3D`: Orient camera in an oblique view for showing 3D objects. Often used to force an Example sub-block to generate an image in Function and Constant blocks.
- `VPD=440`: Force viewpoint distance `$vpd` to 440.
- `VPT=[10,20,30]` Force the viewpoint translation `$vpt` to `[10,20,30]`.
- `VPR=[55,0,600]` Force the viewpoint rotation `$vpr` to `[55,0,60]`.
- `Spin`: Animate camera orbit around the `[0,1,1]` axis to display all sides of an object.
- `FlatSpin`: Animate camera orbit around the Z axis, above the XY plane.
- `Anim`: Make an animation where `$t` varies from `0.0` to almost `1.0`.
- `FrameMS=250`: Sets the number of milliseconds per frame for spins and animation.
- `Frames=36`: Number of animation frames to make.
- `Small`: Make the image small sized.
- `Med`: Make the image medium sized.
- `Big`: Make the image big sized.
- `Huge`: Make the image huge sized.
- `Size=880x640`: Make the image 880 by 640 pixels in size.
- `Render`: Force full rendering from OpenSCAD, instead of the normal preview.
- `Edges`: Highlight face edges.
- `NoAxes`: Hides the axes and scales.
- `ScriptUnder`: Display script text under image, rather than beside it.

Modules will default to generating and displaying the image as if the `3D`
directive is given.  Functions and constants will default to not generating
an image unless `3D`, `Spin`, `FlatSpin` or `Anim` is explicitly given.

If any lines of the Example script begin with `--`, then they are not shown in
the example script output to the documentation, but they *are* included in the
script used to generate the example image, without the `--`, of course:

    // Example: Multi-line example.
    //   --$fn = 72; // Lines starting with -- aren't shown in docs example text.
    //   lst = [
    //       "multi-line examples",
    //       "are shown in one block",
    //       "with a single image.",
    //   ];
    //   foo(lst, 23, "blah");

Creating Custom Block Headers
=============================

If you have need of a non-standard documentation block in your docs, you can declare the new block type using `DefineHeader:`.  This has the syntax:

    // DefineHeader(TYPE): NEWBLOCKNAME

or:

    // DefineHeader(TYPE;OPTIONS): NEWBLOCKNAME

Where NEWBLOCKNAME is the name of the new block header, OPTIONS is an optional list of zero or more semicolon-separated header options, and TYPE defines the behavior of the new block.  TYPE can be one of:

- `Generic`: Show both the TitleText and body.
- `Text`: Show the TitleText as the first line of the body.
- `Headerless`: Show the TitleText as the first line of the body, with no header line.
- `Label`: Show only the TitleText and no body.
- `NumList`: Shows TitleText, and the body lines in a numbered list.
- `BulletList`: Shows TitleText, and the body lines in a bullet list.
- `Table`: Shows TitleText, and body lines in a definition table.
- `Figure`: Shows TitleText, and an image rendered from the script in the Body.
- `Example`: Like Figure, but also shows the body as an example script.

The OPTIONS are zero or more semicolon separated options for defining the header options.  Some of them only require the option name, like `Foo`, and some have an option name and a value separated by an equals sign, like `Foo=Bar`.  There is currently only one option common to all header types:

- `ItemOnly`: Specify that the new header is only allowed as part of the documentation block for a Constant, Function, or Module.

Generic Block Type
------------------

The Generic block header type takes both title and body lines and generates a markdown block that has the block header, title, and a following body:

    // DefineHeader(Generic): Result
    // Result: For Typical Cases
    //   Does typical things.
    //   Or something like that.
    //   Refer to {{stuff()}} for more info.
    // Result: For Atypical Cases
    //   Performs an atypical thing.

Which outputs Markdown code that renders like:

> **Result:** For Typical Cases
>
> Does typical things.
> Or something like that.
> Refer to [stuff()](foobar.scad#function-stuff) for more info.
>
> **Result:** For Atypical Cases
>
> Performs an atypical thing.
>

Text Block Type
---------------

The Text block header type is similar to the Generic type, except it merges the title into the body.  This is useful for allowing single-line or multi-line blocks:

    // DefineHeader(Text): Reason
    // Reason: This is a simple reason.
    // Reason: This is a complex reason.
    //   It is a multi-line explanation
    //   about why this does what it does.
    //   Refer to {{nonsense()}} for more info.

Which outputs Markdown code that renders like:

> **Reason:**
>
> This is a simple reason.
>
> **Reason:**
>
> This is a complex reason.
> It is a multi-line explanation
> about why this does what it does.
> Refer to [nonsense()](foobar.scad#function-nonsense) for more info.
>

Headerless Block Type
---------------------

The Headerless block header type is similar to the Generic type, except it merges the title into the body, and generates no header line.

    // DefineHeader(Headerless): Explanation
    // Explanation: This is a simple explanation.
    // Explanation: This is a complex explanation.
    //   It is a multi-line explanation
    //   about why this does what it does.
    //   Refer to {{nonsense()}} for more info.

Which outputs Markdown code that renders like:

> This is a simple explanation.
>
> This is a complex explanation.
> It is a multi-line explanation
> about why this does what it does.
> Refer to [nonsense()](foobar.scad#function-nonsense) for more info.
>

Label Block Type
----------------

The Label block header type takes just the title, and shows it with the header:

    // DefineHeader(Label): Regions
    // Regions: Antarctica, New Zealand
    // Regions: Europe, Australia

Which outputs Markdown code that renders like:

> **Regions:** Antarctica, New Zealand
> **Regions:** Europe, Australia

NumList Block Type
------------------

The NumList block header type takes both title and body lines, and outputs a
numbered list block:

    // DefineHeader(NumList): Steps
    // Steps: How to handle being on fire.
    //   Stop running around and panicing.
    //   Drop to the ground.  Refer to {{drop()}}.
    //   Roll on the ground to smother the flames.

Which outputs Markdown code that renders like:

> **Steps:** How to handle being on fire.
>
> 1. Stop running around and panicing.
> 2. Drop to the ground.  Refer to [drop()](foobar.scad#function-drop).
> 3. Roll on the ground to smother the flames.
>

BulletList Block Type
---------------------

The BulletList block header type takes both title and body lines:

    // DefineHeader(BulletList): Side Effects
    // Side Effects: For Typical Uses
    //   The variable {{$foo}} gets set.
    //   The default for subsequent calls is updated.

Which outputs Markdown code that renders like:

> **Side Effects:** For Typical Uses
>
> - The variable [$foo](foobar.scad#function-foo) gets set.
> - The default for subsequent calls is updated.
>

Table Block Type
----------------

The Table block header type outputs a header block with the title, followed by one or more tables.  This is generally meant for definition lists.  The header names are given as the `Headers=` option in the DefineHeader metadata.  Header names are separated by `|` (vertical bar, or pipe) characters, and sets of headers (for multiple tables) are separated by `||` (two vertical bars).  A header that starts with the `^` (hat, or circumflex) character, will cause the items in that column to be surrounded by \`foo\` literal markers.  Cells in the body content are separated by `=` (equals signs):

    // DefineHeader(Table;Headers=^Link Name|Description): Anchors
    // Anchors: by Name
    //   "link1" = Anchor for the joiner Located at the {{BACK}} side of the shape.
    //   "a"/"b" = Anchor for the joiner Located at the {{FRONT}} side of the shape.

Which outputs Markdown code that renders like:

> **Anchors:** by Name
>
> Link Name      | Description
> -------------- | --------------------
> `"link1"`      | Anchor for the joiner at the [BACK](constants.scad#constant-back) side of the shape.
> `"a"` / `"b"`  | Anchor for the joiner at the [FRONT](constants.scad#constant-front) side of the shape.
>

You can have multiple subtables, separated by a line with only three dashes: `---`:

    // DefineHeader(Table;Headers=^Pos Arg|What it Does||^Names Arg|What it Does): Args
    // Args:
    //   foo = The foo argument.
    //   bar = The bar argument.
    //   ---
    //   baz = The baz argument.
    //   qux = The baz argument.

Which outputs Markdown code that renders like:

> **Args:**
>
> Pos Arg     | What it Does
> ----------- | --------------------
> `foo`       | The foo argument.
> `bar`       | The bar argument.
>
> Named Arg   | What it Does
> ----------- | --------------------
> `baz`       | The baz argument.
> `qux`       | The qux argument.
>

Defaults Configuration
======================

The `openscad_decsgen` script looks for an `.openscad_docsgen_rc` file in the source code directory it is run in.  In that file, you can give a few defaults for what files will be processed, and where to save the generated documentation.

---

To specify what directory to write the output documentation to, you can use the DocsDirectory block:

    DocsDirectory: wiki_dir

---

To specify what target profile to output for, use the TargetProfile block.  You must specify either `wiki` or `githubwiki` as the value:

    TargetProfile: githubwiki

---

To specify what the project name is, use the ProjectName block, like this:

    ProjectName: My Project Name

---

To specify what types of files will be generated, you can use the GenerateDocs block.  You give it a comma separated list of docs file types like this:

    GenerateDocs: Files, ToC, Index, Topics, CheatSheet, Sidebar

Where the valid docs file types are as follows:

- `Files`: Generate a documentation file for each .scad input file.  Generates Images.
- `ToC`: Generate a project-wide Table of Contents file.
- `Index`: Generate an alphabetically sorted function/module/constants index file.
- `Topics`: Generate an index file of topics, sorted alphabetically.
- `CheatSheet`: Generate a CheatSheet summary of function/module Usages.
- `Cheat`: The same as `CheatSheet`.
- `Sidebar`: Generate a \_Sidebar index of files.

---

To ignore specific files, to prevent generating documentation for them, you can use the IgnoreFiles block.   Note that the commentline prefix is not needed in the configuration file:

    IgnoreFiles:
      ignored1.scad
      ignored2.scad
      tmp_*.scad

---

To prioritize the ordering of files when generating the Table of Contents and other indices, you can use the PrioritizeFiles block:

    PrioritizeFiles:
      file1.scad
      file2.scad

---

You can also use the DefineHeader block in the config file to make custom block headers:

    DefineHeader(Text;ItemOnly): Returns
    DefineHeader(BulletList): Side Effects
    DefineHeader(Table;Headers=^Anchor Name|Position): Extra Anchors

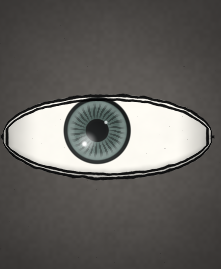
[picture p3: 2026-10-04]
simulator/images/s1/flipbook-frame-009.png

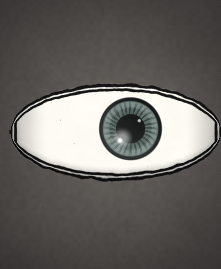
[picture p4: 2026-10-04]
simulator/images/s1/flipbook-frame-004.png

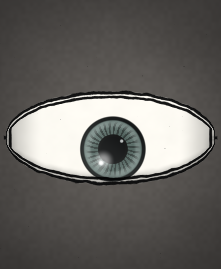
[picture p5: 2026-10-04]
simulator/images/s1/flipbook-frame-000.png

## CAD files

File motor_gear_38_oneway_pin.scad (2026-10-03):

// motor_gear_38_oneway_gear.stl / cover.stl 専用の印刷ピン試作。
// 元設計はM2.5樹脂用ねじ。ギア穴φ2.2、蓋穴φ2.9、蓋厚1.8mm。
// 3本使用。大きな頭を下に印刷。ギア・蓋の変更は不要。
// 差込み長8mm、ギアへの挿入6.2mm、穴底まで0.8mmの余裕。
// まず1本で確認。保持は摩擦頼みで、ねじと同等の保持力はない。
// 緩く抜ける場合は使用せず、shaft_dを少し増やして再印刷する。
// 6個鼓形版のφ3.1ピンとは互換性なし。
shaft_d = 2.1; // φ2.2の既存穴へ入りやすさを優先。保持力は実物で確認。
cover_guide_d = 2.75;
cover_guide_h = 1.6;
head_h = 4;
grip_h = 3;
insert_h = 8;
tip_h = 0.6;
$fn = 128;
eps = 0.01;
assert(shaft_d>1.5 && shaft_d<cover_guide_d);
difference() {
 union() {
  intersection() {
   cylinder(d=8,h=grip_h);
   translate([-2.5,-4,0]) cube([5,8,grip_h]);
  }
  translate([0,0,grip_h-eps]) cylinder(d=4.8,h=head_h-grip_h+eps);
  translate([0,0,head_h-eps]) cylinder(d=cover_guide_d,h=cover_guide_h+eps);
  translate([0,0,head_h+cover_guide_h-eps]) cylinder(d=shaft_d,h=insert_h-cover_guide_h-tip_h+eps);
  translate([0,0,head_h+insert_h-tip_h]) cylinder(d1=shaft_d,d2=shaft_d-0.5,h=tip_h);
 }
 translate([-0.25,-2,head_h+cover_guide_h+0.8]) cube([0.5,4,insert_h]);
}

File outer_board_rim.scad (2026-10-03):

// φ300 mm丸板に側面からネジ止めする外周リング。単位: mm
// 内径300.6 mmで、丸板との径方向の隙間は片側0.3 mm。
// 同一の120度パーツを3個印刷し、それぞれ丸板に固定する。
// 両端の蟻継ぎを上下にスライドして接続する。
// 底面z=0を丸板の底面に揃える。横穴の中心高さは10 mm。
// 穴径4 mmは仮設定。使用するネジの軸径に合わせて変更する。
// CLI: openscad -o outer_board_rim_segment.stl outer_board_rim.scad

$fn = 240;
inner_diameter = 300.6;
wall_thickness = 5;
rim_height = 30;
screw_hole_diameter = 4;
screw_hole_height = 10;
segment_count = 3;

// 5 mmの壁内に収めた蟻継ぎ。凹側は各方向へ0.25 mm広げる。
joint_clearance = 0.25;
joint_depth = 3;
joint_neck_width = 2;
joint_head_width = 3;

// 指定内径に追加する径方向の片側すき間。0なら内径300.6 mm。
radial_clearance = 0;
// "segment": 印刷用 / "assembly": 組立 / "preview": 丸板付き
render_part = "segment";
board_diameter = 300;
board_thickness = 18;

inner_radius = inner_diameter / 2 + radial_clearance;
outer_radius = inner_radius + wall_thickness;
segment_angle = 360 / segment_count;
joint_radius = (inner_radius + outer_radius) / 2;

assert(segment_count == 3, "This part uses three 120-degree segments");
assert(inner_diameter > 0 && wall_thickness > 0 && rim_height > 0);
assert(radial_clearance >= 0);
assert(joint_clearance >= 0 && joint_depth > 0);
assert(joint_neck_width > 0 && joint_head_width > joint_neck_width);
assert(joint_radius - joint_head_width / 2 - joint_clearance > inner_radius
    && sqrt(pow(joint_radius + joint_head_width / 2, 2)
          + pow(joint_depth, 2)) + joint_clearance < outer_radius,
    "Dovetail sockets must leave material on both sides of the wall");
assert(screw_hole_diameter > 0);
assert(screw_hole_height > screw_hole_diameter / 2
    && screw_hole_height + screw_hole_diameter / 2 < rim_height,
    "Screw holes must fit within the wall height");

module joint_prism(angle, clearance = 0) {
    rotate([0, 0, angle])
        translate([joint_radius, 0, 0])
            linear_extrude(height = rim_height)
                offset(delta = clearance)
                    polygon([
                        [-joint_neck_width / 2, -1],
                        [ joint_neck_width / 2, -1],
                        [ joint_neck_width / 2, 0],
                        [ joint_head_width / 2, joint_depth],
                        [-joint_head_width / 2, joint_depth],
                        [-joint_neck_width / 2, 0]
                    ]);
}

module rim_segment() {
    difference() {
        union() {
            rotate([0, 0, -segment_angle / 2])
                rotate_extrude(angle = segment_angle, convexity = 10)
                    translate([inner_radius, 0])
                        square([wall_thickness, rim_height]);
            joint_prism(segment_angle / 2);
        }

        // 反対側の端に、隣のパーツの凸部が入る凹部を設ける。
        translate([0, 0, -1])
            linear_extrude(height = rim_height + 2)
                projection(cut = false)
                    joint_prism(-segment_angle / 2, joint_clearance);

        // 円の中心へ向く水平の貫通穴。端面から各30度の位置。
        for (angle = [-segment_angle / 4, segment_angle / 4])
            rotate([0, 0, angle])
                translate([inner_radius - 1, 0, screw_hole_height])
                    rotate([0, 90, 0])
                        cylinder(h = wall_thickness + 2,
                                 d = screw_hole_diameter, $fn = 64);
    }
}

module assembly() {
    for (i = [0 : segment_count - 1])
        color(i % 2 == 0 ? "darkorange" : "gold")
            rotate([0, 0, i * segment_angle]) rim_segment();
}

if (render_part == "segment") {
    // 45度回転し、XYの中央付近へ移動。底面はz=0。
    shift = -(outer_radius + outer_radius * cos(105)) / 2;
    translate([shift, shift, 0]) rotate([0, 0, 45]) rim_segment();
} else if (render_part == "assembly") {
    assembly();
} else if (render_part == "preview") {
    assembly();
    %color([0.58, 0.36, 0.18, 0.5])
        cylinder(d = board_diameter, h = board_thickness);
} else {
    assert(false, "render_part must be segment, assembly or preview");
}

echo(str("Inner diameter: ", inner_radius * 2, " mm"));
echo(str("Outer diameter: ", outer_radius * 2, " mm"));
echo(str("Height: ", rim_height, " mm"));
echo(str("Horizontal screw holes: diameter ", screw_hole_diameter,
         " mm, center height ", screw_hole_height, " mm"));

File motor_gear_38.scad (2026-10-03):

// モータ用38歯ギア / 単位 mm
// 穴の設定: F7 / 片側すき間0.06 mm（ユーザー指定）。
// まずrender_part="fit_test"を出力して軸へのはまり具合を確認。
include <BOSL2/std.scad>
include <BOSL2/gears.scad>

render_part = "gear"; // "gear" または "fit_test"
gear_teeth = 38;
gear_circular_pitch = 6.5;
gear_pressure_angle = 20;
gear_thickness = 13; // 有効軸長13 mmに対し1 mmの余裕
gear_backlash = 0.15; // ピッチ円上の歯厚を減らす量

shaft_diameter = 8;
shaft_length = 13;
shaft_flat_to_back = 7; // F7: 公称の平面から反対側の円弧までの距離
shaft_clearance = 0.06; // 各面のすき間。穴の円弧径8.12 mm、平面～反対側7.12 mm
entry_chamfer = 0.4;
fit_test_thickness = 3;

$fn = 160;
$gear_steps = 16;
epsilon = 0.01;

assert(shaft_flat_to_back > shaft_diameter/2
       && shaft_flat_to_back < shaft_diameter,
       "Dカット寸法は軸半径より大きく、直径より小さくしてください");
assert(shaft_clearance >= 0 && entry_chamfer >= 0);
assert(gear_thickness > 2*entry_chamfer && gear_thickness <= shaft_length);

// +X側がDカットの平面。公称輪郭を全方向に一定量拡張する。
module shaft_profile(extra = 0) {
    offset(delta = shaft_clearance + extra)
        intersection() {
            circle(d = shaft_diameter);
            translate([-shaft_diameter, -shaft_diameter])
                square([shaft_diameter + shaft_flat_to_back
                        - shaft_diameter/2, 2*shaft_diameter]);
        }
}

module shaft_hole(height) {
    translate([0, 0, -epsilon])
        linear_extrude(height = height + 2*epsilon)
            shaft_profile();
    // 両側の挿入口を面取り。中間部分のD形状は維持。
    if (entry_chamfer > 0) {
        hull() {
            translate([0, 0, -epsilon])
                linear_extrude(height = epsilon)
                    shaft_profile(entry_chamfer);
            translate([0, 0, entry_chamfer])
                linear_extrude(height = epsilon) shaft_profile();
        }
        hull() {
            translate([0, 0, height-entry_chamfer-epsilon])
                linear_extrude(height = epsilon) shaft_profile();
            translate([0, 0, height])
                linear_extrude(height = epsilon)
                    shaft_profile(entry_chamfer);
        }
    }
}

function motor_gear_specs() = [gear_teeth, gear_circular_pitch,
    gear_pressure_angle, gear_thickness];

module motor_gear() {
    difference() {
        spur_gear(circ_pitch = gear_circular_pitch,
                  teeth = gear_teeth, thickness = gear_thickness,
                  pressure_angle = gear_pressure_angle,
                  backlash = gear_backlash, anchor = BOTTOM);
        shaft_hole(gear_thickness);
    }
}

if (render_part == "gear") {
    motor_gear();
} else if (render_part == "fit_test") {
    difference() {
        cylinder(d = 18, h = fit_test_thickness);
        shaft_hole(fit_test_thickness);
    }
} else {
    assert(false, "render_partはgearまたはfit_testにしてください");
}

echo("Dカット F / 片側すき間", shaft_flat_to_back, shaft_clearance);
echo("ピッチ円直径 mm", 2*pitch_radius(circ_pitch=gear_circular_pitch, teeth=gear_teeth));
echo("歯先外径 mm", 2*outer_radius(circ_pitch=gear_circular_pitch, teeth=gear_teeth));
// D形状は回り止めです。軸方向の抜け止めは別途必要です。

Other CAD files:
motor_gear_38_pivot_pawl.scad
BOSL2/affine.scad
BOSL2/attachments.scad
BOSL2/ball_bearings.scad
BOSL2/beziers.scad
BOSL2/bosl1compat.scad
BOSL2/bottlecaps.scad
BOSL2/builtins.scad
BOSL2/color.scad
BOSL2/comparisons.scad
BOSL2/constants.scad
BOSL2/coords.scad
BOSL2/cubetruss.scad
BOSL2/distributors.scad
BOSL2/drawing.scad
BOSL2/examples/BOSL2logo.scad
BOSL2/examples/attachments.scad
BOSL2/examples/boolean_geometry.scad
BOSL2/examples/fractal_tree.scad
BOSL2/examples/lsystems.scad
BOSL2/examples/orientations.scad
BOSL2/examples/spherical_patch.scad
BOSL2/examples/spring_handle.scad
BOSL2/fnliterals.scad
BOSL2/gears.scad
BOSL2/geometry.scad
BOSL2/hinges.scad
BOSL2/isosurface.scad
BOSL2/joiners.scad
BOSL2/linalg.scad
BOSL2/linear_bearings.scad
BOSL2/lists.scad
BOSL2/masks2d.scad
BOSL2/masks3d.scad
BOSL2/math.scad
BOSL2/metric_screws.scad
BOSL2/miscellaneous.scad
BOSL2/modular_hose.scad
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

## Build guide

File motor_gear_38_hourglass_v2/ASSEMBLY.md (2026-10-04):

# 38歯・6鼓形ローラー版 v2 の組立

ローラーを入れられるようにポケットの広い側を拡大し、蓋の裏に円周状の倒れ止めを追加した試作品です。旧9個版のハブと蓋は使いません。

## 印刷する部品

ファイル名の共通部分は `motor_gear_38_hourglass_v2_` です。

| STL末尾 | 部品 | 個数 |
|---|---|---:|
| gear.stl | 外ギア | 1 |
| hub.stl | 内側ハブ | 1 |
| ring.stl | 下リング | 1 |
| roller.stl | 鼓形ローラー | 6 |
| cover.stl | 突起付き蓋 | 1 |
| pin.stl | 固定ピン | 3 |

全13部品、PETGを想定。各STLの底面を下にして印刷します。蓋は突起が上の姿勢で印刷し、組立時に裏返します。ローラーは中実にし、シーム・バリ・初層の膨らみを除去してください。

## 組立手順

1. 外ギアを平らな台に、くぼみを上にして置きます。
2. 中央穴に下リングを置きます。D穴入口の面取り側が下です。
3. 内側ハブを、中央の突起を上にして置きます。下リングとD穴の向きを合わせます。
4. 各ポケットの広い部分に、ローラーを縦向きで上から入れます。ローラーは上下対称です。挿入位置は中心から半径24 mm、各カム開始から36度の位置です。寸法を測って組み立てる必要はなく、下の挿入位置図を目安にしてください。
5. 底まで入れたら、ローラーを外周側へ約0.86 mm寄せます。挿入位置のままでは蓋の倒れ止めに当たります。
6. 蓋を裏返し、**円周状の突起が下**になるように載せ、固定穴3個を合わせます。突起はローラーの上端より内側に収まります。蓋が浮く場合は押し込まず、ローラーの位置を直します。
7. 固定ピンを、割れた細い側から上面の3穴に差し込みます。ピンの頭は幅8×奥行5 mmで、蓋から4 mm突出します。頭の下の1 mmの隙間を使い、指やペンチでつかんで真上へ引き抜けます。
8. ハブを保持して外ギアを手回しし、一方向の噛み込みと反対方向の解放を確認します。下リングを支えながらモーターのD軸へ取り付けます。

[挿入位置（上面図）](motor_gear_38_hourglass_v2_insert.png) · [外側へ寄せた状態](motor_gear_38_hourglass_v2_open.png) · [蓋の裏側](motor_gear_38_hourglass_v2_cover.png) · [分解図](motor_gear_38_hourglass_v2_exploded.png)

## 倒れ止めと隙間

ローラーは中央φ6.2 mm、上下φ7.4 mm、高さ8.5 mmです。挿入位置では太い部分に対して外ギア側に半径方向0.3 mm、ハブ側には最小約0.67 mmの設計上の余裕があります。

蓋のリング状突起は、通常位置のローラー上端から内側へ0.31 mm離れています。外側の受け面と上下端面も使って姿勢を制限します。カム上端と突起下端は0.3 mm離れており、ハブと蓋の相対回転を許します。ガタや摩擦がゼロになる構造ではありません。

上から見てモーター側ハブが反時計回りに駆動し、かみ合う112歯ターンテーブルが時計回りになる配置です。`reverse_direction` でカムを反転できます。既定STLは反転していません。

## 検証範囲

`verify_geometry.scad` は、ローラー挿入・外側への移動・蓋を下ろす経路と、解放位置・噛み込み直前の干渉を検査します。出力が空集合なら交差なしです。結果は検証ログとJSONを参照してください。

実物の噛み込み、空転抵抗、荷重分担、160 RPM・10 kgf·cmでの耐久性は未検証です。最初は手回しで確認してください。D穴は回り止めで、モーター軸からの抜け止めは別途必要です。

OpenSCADソースは、親フォルダの `motor_gear_38.scad` とその `BOSL2` を参照します。STLの印刷にはこれらは不要です。

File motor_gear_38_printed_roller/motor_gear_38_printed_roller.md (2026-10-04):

# 全印刷・2球式38歯ワンウェイクラッチ

円筒ローラーが倒れて起き上がれなくなる問題への試作として、転動体を **直径6 mmの球2個** に変更した。球はどの向きでも直径が同じなので、円筒のような「立った状態への復帰」を必要としない。既定形状は球。従来の円筒も `roller_shape="cylinder"` で出力できる。

38歯ギア・カム付きハブ・下側リング・蓋・固定ピンの寸法は変更しない。既存部品を使い、転動体2個を交換する試作。ファイル名は互換性のため `motor_gear_38_printed_roller` のままとし、`_roller.stl` の内容が球に変わっている。

## 使い方と出力

`motor_gear_38_printed_roller.scad` をOpenSCADで開く。既定は蓋を除いた内部表示。橙が外側ギア、青がカム付きハブ、黄土色が下側リング、緑が球。

| 設定 | 内容 |
| --- | --- |
| `roller_shape="ball"` | φ6 mmの球（既定） |
| `roller_shape="cylinder"` | 従来のφ6×8.4 mm円筒、上下0.3 mm面取り |
| `roller_state="free" / "wedge"` | 解放位置 / 噛み込み直前 |
| `render_part="open" / "assembly"` | 内部表示 / 蓋とピンを含む組立 |
| `render_part="exploded" / "layout"` | 分解表示 / 必要数の印刷部品配置 |
| `render_part="motion"` | 解放位置と噛み込み直前の間を往復する参考表示 |
| `gear / hub / ring / roller / cover / pin` | 部品単独出力 |

`motion` は位置関係の表示であり、摩擦・転がり・変形のシミュレーションではない。

親フォルダの `../motor_gear_38.scad` と `../BOSL2/` に依存する。このフォルダだけを別の場所へ移さない。

## 印刷するもの

| STL末尾 | 個数 | 形状・印刷方向 |
| --- | ---: | --- |
| `_gear.stl` | 1 | 38歯外側ギア。底面を下。既存品を流用 |
| `_hub.stl` | 1 | D穴カム本体、高さ10.9 mm。平らなカム下面を下。既存品を流用 |
| `_ring.stl` | 1 | 下側支持リング、外径20 mm・厚さ2.1 mm。既存品を流用 |
| `_roller.stl` | 2 | **φ6 mm球。下側にサポートが必要** |
| `_cover.stl` | 1 | 保持蓋。既存品を流用 |
| `_pin.stl` | 3 | 割り入り摩擦保持ピン。頭を下。既存品を流用 |

PETG球は中実で印刷する。平面カットを設けていないため、球単体をそのままベッドに置いたサポートなしの印刷は想定しない。スライサーで下半分を支えるサポートを設定する。0.4 mmノズルなら層厚0.16 mm程度を試作の出発点とするが、造形品質は未検証。

サポート痕・シームの突起・糸引きを除去し、複数方向の直径と滑らかさを確認する。**大きな平面を削り出すと、向きによって接触寸法が変わる。** 球を作る目的に反するため、形を崩すほど削らない。小径球の精度はプリンターに依存する。

```sh
# 既定の球を1個出力（印刷時に2個へ複製）
openscad --hardwarnings -D 'render_part="roller"' -o ball_6mm.stl motor_gear_38_printed_roller.scad

# 従来の円筒を出力
openscad --hardwarnings -D 'render_part="roller"' -D 'roller_shape="cylinder"' -o cylinder_6mm.stl motor_gear_38_printed_roller.scad
```

## 球が収まる位置

- ギア全厚13 mm、外側受け面の半径28 mm、D穴F7 / C0.06は従来どおり。
- 床Z=1.8 mm、蓋下面Z=11.2 mmで、転動体の空間高さは9.4 mm。φ6球には合計3.4 mmの上下移動余裕がある。
- 球の中心は、床に接したときZ=4.8 mm、蓋に接したときZ=8.2 mm。どちらもカム側面のZ=2.1〜10.9 mm内にあり、赤道部分でカムと外周に接触できる。
- 表示では床から0.04 mm浮かせる。横方向も外周・カムへの噛み込み直前に各0.04 mmのすき間を置く。
- 解放角49度、噛み込み直前角約30.31度。直径を維持したので平面上の接触位置は円筒版と同じ。

## 回転方向と組立

+Z（上面）から見てモーターハブを反時計回りに駆動すると、転動体が狭い側で噛む想定。停止後は外側ギアが反時計回りに追い越し、広い側へ移って解放される。112歯ターンテーブルは時計回り。`reverse_direction=true` で鏡像にできる。

1. 下側リングとハブ本体のD穴の平面を揃え、同じ軸に通す。リングの入口面取りを下にする。
2. 広いポケット2箇所へ球を1個ずつ入れる。姿勢合わせは不要。
3. 蓋を付け、印刷ピン3本で保持する。モーター軸全体からの抜け止めは別途必要。
4. 手でハブを固定し、外側ギアが反時計回りに空転し、時計回りに噛むか確認する。
5. 噛ませた直後に逆へ回し、解放できるか確認する。傾けて球が床側・蓋側へ移った後も繰り返す。
6. 続いて無負荷・低速で確認し、球・カム・受け面にへこみが生じていないか調べる。

固定ピンは直径3.3 mm、穴3.15 mmの摩擦保持。挿入力・保持力は実機調整が必要。

## 限界と確認事項

球化で取り除くのは、円筒が倒れたままになる姿勢の問題。バネを追加していないため、狭い側への移動遅れや、摩擦・変形による噛み付きまで解消するものではない。

球は円筒より接触面が小さく、同じ荷重では局所的な変形が懸念される。PETG球やカムがへこんで解放しにくくなる可能性がある。一般的な球の点接触・ローラーの線接触の説明は[SKFの軸受基礎資料（20ページ）](https://cdn.skfmediahub.skf.com/api/public/0901d196802809de/pdf_preview_medium/Rolling_bearings_-_17000_1_EN_pdf_preview_medium.pdf)を参照。この試作の強度評価を示す資料ではない。

指定モーターの表記10 kgf·cm（約0.98 N·m）、160 RPMでの伝達能力・解放・摩耗寿命は未検証。CAD確認は形状と可動空間を対象とし、実負荷性能を保証しない。

## 球形版のCAD確認（2026-10-01）

- OpenSCAD 2021.01の`--hardwarnings`で球のSTLを出力。単一の連結体・閉じたメッシュ・面の向きの整合を確認。
- STL外形は各軸約5.99884 mm（球面の多角形近似）、体積約113.025 mm³。公称φ6球の体積は約113.097 mm³。
- カムの線分との距離を噛み込み直前〜解放位置の41点で計算し、球表面とのすき間が約0.04 mm以上あることを確認。解放位置では約0.710 mm。噛み込み直前から狭い側へ2度進めると約0.032 mm食い込む計算になる。
- 床・蓋それぞれに接したときも、球の赤道がカムの高さ範囲内にあることを確認。これは幾何学的な確認であり、球の運動解析ではない。
- 円筒オプションも再出力し、高さ8.4 mmを確認。
- 内部・分解・印刷配置の画像を球形版へ更新し、目視確認。

## 大きめの球の比較試作

既存のφ6球・ギア・カムを変更せず、球だけ交換する比較用STLを追加した。

| ファイル | 公称径 | 既存カムの解放位置でのすき間（計算値） |
| --- | --- | --- |
| `motor_gear_38_printed_roller_ball_6p1.stl` | 6.1 mm | 約0.61 mm |
| `motor_gear_38_printed_roller_ball_6p2.stl` | 6.2 mm | 約0.51 mm |

各サイズを2個ずつ印刷し、同じ径の球をペアで使う。まず6.1 mmで、噛み始めと解放の軽さを手回し確認し、必要なら6.2 mmを試す。サポート除去・表面仕上げ後の実測径も確認する。形状チェックは通過しているが、噛み合い・解放・耐久性は実機未検証。

書き出し時は `render_part="roller"`、`roller_shape="ball"`、`roller_d=6.1` または `6.2` を指定した。**このSCADではroller_dを変えるとカム寸法も追従するため、この比較では球だけを書き出す。ギアやハブを再生成しない。** 表のすき間は追従後のカムではなく、元の6.0 mm用カムを固定して別計算した値。

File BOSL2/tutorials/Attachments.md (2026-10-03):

# Attachments Tutorial

<!-- TOC -->

## Attachables
BOSL2 introduces the concept of attachables.  You can do the following
things with attachable shapes:

* Control where the shape appears and how it is oriented by anchoring and specifying orientation and spin
* Position or attach shapes relative to parent objects
* Tag objects and then control boolean operations based on their tags.
* Change the color of objects so that child objects are different colors than their parents

The various attachment features may seem complex at first, but 
attachability is one of the most important features of the BOSL2
library.  It enables you to position objects relative to other objects
in your model instead of having to keep track of absolute positions.
It makes models simpler, more intuitive, and easier to maintain.

Almost all objects defined by BOSL2 are attachable.  In addition,
BOSL2 overrides the built-in definitions for `cube()`, `cylinder()`,
`sphere()`, `square()`, `circle()` and `text()` and makes them attachable as
well.  However, some basic OpenSCAD built-in definitions are not
attachable and will not work with the features described in this
tutorial.  The non-attachables are `polyhedron()`, `linear_extrude()`,
`rotate_extrude()`, `surface()`, `projection()` and `polygon()`.
Some of these have attachable alternatives: `vnf_polyhedron()`,
`linear_sweep()`, `rotate_sweep()`, and `region()`.  

## Anchoring
Anchoring allows you to align a specified part of an object or point
on an object with the origin.  The alignment point can be the center
of a side, the center of an edge, a corner, or some other
distinguished point on the object.  This is done by passing a vector
or text string into the `anchor=` argument.  For roughly cubical
or prismoidal shapes, that vector points in the general direction of the side, edge, or
corner that will be aligned to.  For example, a vector of [1,0,-1] refers to the lower-right
edge of the shape.  Each vector component should be -1, 0, or 1:

```openscad-3D
include <BOSL2/std.scad>
// Anchor at upper-front-left corner
cube([40,30,50], anchor=[-1,-1,1]);
```

```openscad-3D
include <BOSL2/std.scad>
// Anchor at upper-right edge
cube([40,30,50], anchor=[1,0,1]);
```

```openscad-3D
include <BOSL2/std.scad>
// Anchor at bottom face
cube([40,30,50], anchor=[0,0,-1]);
```

Since manually written vectors are not very intuitive, BOSL2 defines some standard directional
vector constants that can be added together:

Constant | Direction | Value
-------- | --------- | -----------
`LEFT`   | X-        | `[-1, 0, 0]`
`RIGHT`  | X+        | `[ 1, 0, 0]`
`FRONT`/`FORWARD`/`FWD` | Y− | `[ 0, −1, 0]`
`BACK`   | Y+        | `[ 0, 1, 0]`
`BOTTOM`/`BOT`/`DOWN` | Z− (Y− in 2D) | `[ 0, 0, −1]` (`[0, −1]` in 2D.)
`TOP`/`UP` | Z+ (Y+ in 2D)      | `[ 0, 0, 1]` (`[0, 1]` in 2D.)
`CENTER`/`CTR` | Centered | `[ 0, 0, 0]`

If you want a vector pointing towards the bottom−left edge, just add the `BOTTOM` and `LEFT` vector
constants together like `BOTTOM + LEFT`.  This will result in a vector of `[−1,0,−1]`.  You can pass
that to the `anchor=` argument for a clearly understandable anchoring:  

```openscad-3D
include <BOSL2/std.scad>
cube([40,30,50], anchor=BACK+TOP);
```

```openscad-3D
include <BOSL2/std.scad>
cube([40,30,50], anchor=FRONT);
```

---

For cylindrical type attachables, the Z component of the vector will be −1, 0, or 1, referring
to the bottom rim, the middle side, or the top rim of the cylindrical or conical shape.
The X and Y components can be any value, pointing towards the circular perimeter of the cone.
These combined let you point at any place on the bottom or top rims, or at an arbitrary
side wall. 

```openscad-3D
include <BOSL2/std.scad>
cylinder(r1=25, r2=15, h=60, anchor=TOP+LEFT);
```

```openscad-3D
include <BOSL2/std.scad>
cylinder(r1=25, r2=15, h=60, anchor=BOTTOM+FRONT);
```

Here we convert a 30 deg angle into an anchor using [cylindrical_to_xyz()](https://github.com/BelfrySCAD/BOSL2/wiki/coords.scad#function-cylindrical_to_xyz)

```openscad-3D
include <BOSL2/std.scad>
cylinder(r1=25, r2=15, h=60, anchor=cylindrical_to_xyz(1,30,1));
```

---

For Spherical type attachables, you can pass a vector that points at any arbitrary place on
the surface of the sphere:

```openscad-3D
include <BOSL2/std.scad>
sphere(r=50, anchor=TOP);
```

```openscad-3D
include <BOSL2/std.scad>
sphere(r=50, anchor=TOP+FRONT);
```

Here the [spherical_to_xyz()](https://github.com/BelfrySCAD/BOSL2/wiki/coords.scad#function-spherical_to_xyz) function converts spherical coordinates into
a vector you can use as an anchor:

```openscad-3D
include <BOSL2/std.scad>
sphere(r=50, anchor=spherical_to_xyz(1,-30,60));
```

---

Some attachable shapes may provide specific named anchors for shape-specific anchoring.  These
will be given as strings and will be specific to that type of
attachable.  When named anchors are supported, they are listed in a
"Named Anchors" section of the documentation for the module.  The
`teardrop()` attachable, for example, has a named anchor called "cap" and in 2D the
`star()` attachable has anchors labeled by tip number: 

```openscad-3D
include <BOSL2/std.scad>
teardrop(d=100, l=20, anchor="cap");
```

```openscad-2D
include <BOSL2/std.scad>
star(n=7, od=30, id=20, anchor="tip2");
```

---

Some shapes, for backwards compatibility reasons, can take a `center=` argument.  This just
overrides the `anchor=` argument.  A `center=true` argument is the same as `anchor=CENTER`.
A `center=false` argument chooses the anchor to match the behavior of
the builtin version:  for a cube it is the same as `anchor=[-1,-1,-1]` but for a
cylinder, it is the same as `anchor=BOTTOM`.

```openscad-3D
include <BOSL2/std.scad>
cube([50,40,30],center=true);
```

```openscad-3D
include <BOSL2/std.scad>
cube([50,40,30],center=false);
```

---

Most 2D shapes provided by BOSL2 are also anchorable.  The built-in `square()` and `circle()`
modules have been overridden to make them attachable..  The `anchor=` options for 2D
shapes treat 2D vectors as expected.  Special handling occurs with 3D
vectors:  if the Y coordinate is zero and the Z coordinate is nonzero,
then the Z coordinate is used to replace the Y coordinate.  This is
done so that you can use the TOP and BOTTOM names as anchor for 2D
shapes.  

```openscad-2D
include <BOSL2/std.scad>
square([40,30], anchor=BACK+LEFT);
```

```openscad-2D
include <BOSL2/std.scad>
circle(d=50, anchor=BACK);
```

```openscad-2D
include <BOSL2/std.scad>
hexagon(d=50, anchor=LEFT);
```

```openscad-2D
include <BOSL2/std.scad>
ellipse(d=[50,30], anchor=FRONT);

This final 2D example shows using the 3D anchor, TOP, with a 2D
object.  Also notice how the pentagon anchors to its most extreme point on
the Y+ axis.  

```openscad-2D
include <BOSL2/std.scad>
pentagon(d=50, anchor=TOP);
```

## Spin
You can spin attachable objects around the origin using the `spin=`
argument.  The spin applies **after** anchoring, so depending on how
you anchor an object, its spin may not be about its center.  This
means that spin can have an effect even on rotationally symmetric
objects like spheres and cylinders.  You specify the spin in degrees.
A positive number will result in a counter-clockwise spin around the Z
axis (as seen from above), and a negative number will make a clockwise
spin:

```openscad-3D
include <BOSL2/std.scad>
cube([20,20,40], center=true, spin=45);
```

This example shows a cylinder which has been anchored at its FRONT,
with a rotated copy in gray.  The rotation is performed around the
origin, but the cylinder is off the origin, so the rotation **does**
have an effect on the cylinder, even though the cylinder has
rotational symmetry.

```openscad-3D
include <BOSL2/std.scad>
cylinder(h=40,d=20,anchor=FRONT+BOT);
%cylinder(h=40.2,d=20,anchor=FRONT+BOT,spin=40);
```

You can also apply spin to 2D shapes from BOSL2, though only by scalar angle:

```openscad-2D
include <BOSL2/std.scad>
square([40,30], spin=30);
```

```openscad-2D
include <BOSL2/std.scad>
ellipse(d=[40,30], spin=30);
```

## Orientation
Another way to specify a rotation for an attachable shape, is to pass a 3D vector via the
`orient=` argument.  This lets you specify what direction to tilt the top of the shape towards.
For example, you can make a cone that is tilted up and to the right like this:

```openscad-3D
include <BOSL2/std.scad>
cylinder(h=100, r1=50, r2=20, orient=UP+RIGHT);
```

More precisely, the Z direction of the shape is rotated to align with
the vector you specify.  Two dimensional attachables, which have no Z vector,
do not accept the `orient=` argument.  

## Mixing Anchoring, Spin, and Orientation
When giving `anchor=`, `spin=`, and `orient=`, they are applied anchoring first, spin second,
then orient last.  For example, here's a cube:

```openscad-3D
include <BOSL2/std.scad>
cube([20,20,50]);
```

You can center it with an `anchor=CENTER` argument:

```openscad-3D
include <BOSL2/std.scad>
cube([20,20,50], anchor=CENTER);
```

Add a 45 degree spin:

```openscad-3D
include <BOSL2/std.scad>
cube([20,20,50], anchor=CENTER, spin=45);
```

Now tilt the top up and forward:

```openscad-3D
include <BOSL2/std.scad>
cube([20,20,50], anchor=CENTER, spin=45, orient=UP+FWD);
```

For 2D shapes, you can mix `anchor=` with `spin=`, but not with `orient=`.

```openscad-2D
include <BOSL2/std.scad>
square([40,30], anchor=BACK+LEFT, spin=30);
```

## Positioning Children

Positioning is a powerful method for placing an object relative to
another object.  You do this by making the second object a child of
the first object.  By default, the child's anchor point will be
aligned with the center of the parent.  The default anchor for `cyl()`
is CENTER, and in this case, the cylinder is centered on the cube's center

```openscad-3D
include <BOSL2/std.scad>
up(13) cube(50)
    cyl(d=25,l=95);
```

With `cylinder()` the default anchor is BOTTOM.  It's hard to tell,
but the cylinder's bottom is placed at the center of the cube.  

```openscad-3D
include <BOSL2/std.scad>
cube(50)
    cylinder(d=25,h=75);
```

If you explicitly anchor the child object then the anchor you choose will be aligned
with the center point of the parent object.  In this example the right
side of the cylinder is aligned with the center of the cube.  

```openscad-3D
include <BOSL2/std.scad>
cube(50,anchor=FRONT)     
    cylinder(d=25,h=95,anchor=RIGHT);
```

The `position()` module enables you to specify where on the parent to
position the child object.  You give `position()` an anchor point on
the parent, and the child's anchor point is aligned with the specified
parent anchor point.  In this example the LEFT anchor of the cylinder is positioned on the
RIGHT anchor of the cube.  

```openscad-3D
include <BOSL2/std.scad>
cube(50,anchor=FRONT)     
    position(RIGHT) cylinder(d=25,h=75,anchor=LEFT);
```

Using this mechanism you can position objects relative to other
objects which are in turn positioned relative to other objects without
having to keep track of the transformation math.

```openscad-3D
include <BOSL2/std.scad>
cube([50,50,30],center=true)
    position(TOP+RIGHT) cube([25,40,10], anchor=RIGHT+BOT)
       position(LEFT+FRONT+TOP) cube([12,12,8], anchor=LEFT+FRONT+BOT)
         cylinder(h=10,r=3);
```

The positioning mechanism is not magical: it simply applies a
`translate()` operation to the child.  You can still apply your own
additional translations or other transformations if you wish.  For
example, you can position an object 5 units from the right edge:

```openscad-3D
include<BOSL2/std.scad>
cube([50,50,20],center=true)
    position(TOP+RIGHT) left(5) cube([4,50,10], anchor=RIGHT+BOT);
```

Positioning objects works the same way in 2D.

```openscad-2D
include<BOSL2/std.scad>
square(10)
    position(RIGHT) square(3,anchor=LEFT);
```

## Using position() with orient()

When positioning an object near an edge or corner you may wish to
orient the object relative to some face other than the TOP face that
meets at that edge or corner.  You can always apply `rot()` to 
change the orientation of the child object, but in order to do this,
you need to figure out the correct rotation.  The `orient()` module provides a
mechanism for re-orienting the child() that eases this burden: 
it can orient the child relative to the parent anchor directions.  This is different
than giving an `orient=` argument to the child, because that orients
relative to the parent's global coordinate system by just using the vector
directly, instead of orienting to the parent's anchor, which takes
account of face orientation.  A series of three
examples shows the different results.  In the first example, we use
only `position()`.  The child cube is erected pointing upwards, in the
Z direction.  In the second example we use `orient=RIGHT` in the child
and the result is that the child object points in the X+ direction,
without regard for the shape of the parent object.  In the final
example we apply `orient(RIGHT)` and the child is oriented
relative to the slanted right face of the parent using the parent
RIGHT anchor.   

```openscad-3D
include<BOSL2/std.scad>
prismoid([50,50],[30,30],h=40)
  position(RIGHT+TOP)
     cube([15,15,25],anchor=RIGHT+BOT);
```

```openscad-3D
include<BOSL2/std.scad>
prismoid([50,50],[30,30],h=40)
  position(RIGHT+TOP)
     cube([15,15,25],orient=RIGHT,anchor=LEFT+BOT);
```

```openscad-3D
include<BOSL2/std.scad>
prismoid([50,50],[30,30],h=40)
  position(RIGHT+TOP)
     orient(RIGHT)
        cube([15,15,25],anchor=BACK+BOT);
```

You may have noticed that the children in the above three examples
have different anchors.  Why is that?  The first and second examples
differ because anchoring up and anchoring to the right require
anchoring on opposite sides of the child.  But the third case differs
because the spin has changed.  The examples below show the same models
but with arrows replacing the child cube.  The red flags on the arrows
mark the zero spin direction.  Examine the red flags to see how the spin
changes.  The Y+ direction of the child will point towards that red
flag.  

```openscad-3D
include<BOSL2/std.scad>
prismoid([50,50],[30,30],h=40)
  position(RIGHT+TOP)
     anchor_arrow(40);
```

```openscad-3D
include<BOSL2/std.scad>
prismoid([50,50],[30,30],h=40)
  position(RIGHT+TOP)
     anchor_arrow(40, orient=RIGHT);
```

```openscad-3D
include<BOSL2/std.scad>
prismoid([50,50],[30,30],h=40)
  position(RIGHT+TOP)
     orient(RIGHT)
        anchor_arrow(40);
```

## Aligning children with align()

You may have noticed that with position() and orient(), specifying the
child anchors to position objects flush with their parent can be
annoying, or sometimes even tricky.  You can simplify this task by
using the align() module.  This module positions children on faces
of a parent and aligns to edges or corners, while picking the correct anchor points on
the children so that the children line up correctly with the parent.  

In the simplest case, if you want to place a child on the RIGHT side
of its parent, you need to anchor the child to its LEFT anchor:

```openscad-3D
include<BOSL2/std.scad>
cuboid([50,40,15])
    position(RIGHT)
        color("lightblue")cuboid(5,anchor=LEFT);
```

When you use align() it automatically determines the correct anchor to
use for the child and this anchor overrides any anchor specified to
the child:  any anchor you specify for the child is ignored.

```openscad-3D
include<BOSL2/std.scad>
cuboid([50,40,15])
    align(RIGHT)
        color("lightblue")cuboid(5);
```

To place the child on top of the parent in the corner you can do use
align as shown below instead of specifying the RIGHT+FRONT+BOT anchor
with position(): 

```openscad-3D
include<BOSL2/std.scad>
cuboid([50,40,15])
    align(TOP,RIGHT+FRONT)
        color("lightblue")prismoid([10,5],[7,4],height=4);
```

Both position() and align() can accept a list of anchor locations and
makes several copies of the children, but
if you want the children positioned flush, each copy 
requires a different anchor, so it is impossible to do this with a
single call to position(), but easily done using align():

```openscad-3D
include<BOSL2/std.scad>
cuboid([50,40,15])
    align(TOP,[RIGHT,LEFT])
        color("lightblue")prismoid([10,5],[7,4],height=4);
```

If you want the children close to the edge but not actually flush you
can use the `inset=` parameter of align to achieve this:

```openscad-3D
include<BOSL2/std.scad>
cuboid([50,40,15])
    align(TOP,[FWD,RIGHT,LEFT,BACK],inset=3)
        color("lightblue")prismoid([10,5],[7,4],height=4);
```

If you spin the children then align will still do the right thing

```openscad-3D
include<BOSL2/std.scad>
cuboid([50,40,15])
    align(TOP,[RIGHT,LEFT])
        color("lightblue")prismoid([10,5],[7,4],height=4,spin=90);
```

If you orient the object DOWN it will be attached from its top anchor,
correctly aligned.  

```openscad-3D
include<BOSL2/std.scad>
cuboid([50,40,15])
    align(TOP,RIGHT)
        color("lightblue")prismoid([10,5],[7,4],height=4,orient=DOWN);
```

Note that align() never changes the orientation of the children.  If
you put the blue prismoid on the right side the anchors line up but
the edges of the child and parent don't.

```openscad-3D
include<BOSL2/std.scad>
prismoid(50,30,25){
  align(RIGHT,TOP)
    color("lightblue")prismoid([10,5],[7,4],height=4);
}
```

If you apply spin that is not a multiple of 90 degrees then alignment
will line up the corner

```openscad-3D
include<BOSL2/std.scad>
cuboid([50,40,15])
    align(TOP,RIGHT)
        color("lightblue")cuboid(8,spin=33);
```

You can also attach objects to a cylinder.  If you use the usual cubic
anchors then a cube will attach on a face as shown here:

```openscad-3D
include<BOSL2/std.scad>
cyl(h=20,d=10,$fn=128)
  align(RIGHT,TOP)
    color("lightblue")cuboid(5);
```

But with a cylinder you can choose an arbitrary horizontal angle for
the anchor.  If you do this, similar to the case of arbitrary spin,
the cube will attach on the nearest corner.

```openscad-3D
include<BOSL2/std.scad>
cyl(h=20,d=10,$fn=128)
  align([1,.3],TOP)
    color("lightblue")cuboid(5);
```

## Attachment overview

Attachables get their name from their ability to be attached to each
other.  Unlike with positioning, attaching changes the orientation of
the child object.  Think of it like sticking two objects together:
when you attach an object, it appears on the parent
relative to the local coordinate system of the parent at the anchor point.  To understand
what this means, imagine the perspective of an ant walking on a
sphere.  The meaning of UP varies depending on where on the sphere the
ant is standing.  If you **attach** a cylinder to the sphere then the cylinder will
be "up" from the ant's perspective.   The first example shows a
cylinder placed with `position()` so it points up in the global parent
coordinate system.  The second example shows how `attach()` points the
cylinder UP from the perspective of an ant standing at the anchor
point on the sphere.  

```openscad-3D
include<BOSL2/std.scad>
sphere(40)
    position(RIGHT+TOP) cylinder(r=8,h=20);
```

```openscad-3D
include<BOSL2/std.scad>
sphere(40)
    attach(RIGHT+TOP) cylinder(r=8,h=20);
```

In the example above, the cylinder's center point is attached to the
sphere, pointing "up" from the perspective of the sphere's surface.
For a sphere, a surface normal is defined everywhere that specifies
what "up" means.  But for other objects, it may not be so obvious.
Usually at edges and corners the direction is the average of the
direction of the faces that meet there.

When you specify an anchor you are actually specifying both an anchor
point but also an anchor direction.  If you want to visualize this
direction you can use anchor arrows.  

## Anchor Directions and Anchor Arrows
For the ant on the sphere it is obvious which direction is UP; that
direction corresponds to the Z+ axis.  The location of the X and Y
axes is less clear and in fact it may be arbitrary.  One way that is
useful to show the position and orientation of an anchor point is by
attaching an anchor arrow to that anchor.  As noted before, the small
red flag points in the direction of the anchor's Y+ axis when the spin
is zero.

```openscad-3D
include <BOSL2/std.scad>
cube(18, center=true)
    attach(LEFT+TOP)
        anchor_arrow();
```

For large objects, you can change the size of the arrow with the `s=` argument.

```openscad-3D
include <BOSL2/std.scad>
sphere(d=100)
    attach(LEFT+TOP)
        anchor_arrow(s=50);
```

To show all the standard cardinal anchor points, you can use the [show_anchors()](https://github.com/BelfrySCAD/BOSL2/wiki/attachments.scad#module-show_anchors) module.

```openscad-3D;Big
include <BOSL2/std.scad>
cube(20, center=true)
    show_anchors();
```

```openscad-3D;Big
include <BOSL2/std.scad>
cylinder(h=25, d=25, center=true)
    show_anchors();
```

```openscad-3D;Big
include <BOSL2/std.scad>
sphere(d=40)
    show_anchors();
```

For large objects, you can again change the size of the arrows with the `s=` argument.

```openscad-3D;Big
include <BOSL2/std.scad>
prismoid(150,60,100)
    show_anchors(s=45);
```

## Parent-Child Anchor Attachment (Double Argument Attachment)

The `attach()` module has two different modes of operation,
parent-child anchor attachment and parent anchor attachment.  These
are also called double argument attachment and single argument
attachment.  The parent-child anchor attachment, with two arguments,
is usually easier to use and is more powerful because it supports
alignment.  When you use parent-child anchor attachment you give a
parent anchor and a child anchor.  Imagine pointing the anchor arrows
on the two objects directly at each other and pushing them together in
the direction of the arrows until they touch.  In many of the examples
below we show first the two objects with their anchor arrows and then
the result of the attach operation using those anchors.

```openscad-3D
include <BOSL2/std.scad>
cube(50,anchor=BOT) attach(TOP,BOT) anchor_arrow(30);
right(60)cylinder(d1=30,d2=15,h=25) attach(BOT,BOT) anchor_arrow(30);
```

```openscad-3D
include <BOSL2/std.scad>
cube(50,anchor=BOT)
  attach(TOP,BOT) cylinder(d1=30,d2=15,h=25);
```

This example produces the same result as using `align()`, but if the
parent anchor is not horizontal, then the child is reoriented:

```openscad-3D
include <BOSL2/std.scad>
prismoid([50,50],[35,35],h=50,anchor=BOT) attach(RIGHT,BOT) anchor_arrow(30);
right(60)cylinder(d1=30,d2=15,h=25) attach(BOT,BOT) anchor_arrow(30);
```

```openscad-3D
include <BOSL2/std.scad>
prismoid([50,50],[35,35],h=50,anchor=BOT)
  attach(RIGHT,BOT) cylinder(d1=30,d2=15,h=25);
```

In this case we attach the curved side of the cone to a cube by lining
up the anchor arrows:

```openscad-3D
include <BOSL2/std.scad>
cube(50,center=true) attach(RIGHT,BOT) anchor_arrow(30);
right(80)cylinder(d1=30,d2=15,h=25) attach(LEFT,BOT) anchor_arrow(30);
```

```openscad-3D
include <BOSL2/std.scad>
cube(50,center=true)
  attach(RIGHT,LEFT) cylinder(d1=30,d2=15,h=25);
```

Note that this form of attachent overrides any anchor or orientation
specified in the child: **with parent-child anchor attachment the
`anchor=` and `orient=` parameters to the child are ignored.**

When you specify attachment using a pair of anchors, the attached
child can spin around the parent anchor while still being attached at
the designated anchors: specifying the anchors leaves one unspecified
degree of freedom.  As noted earlier, this ambiguity is resolved by anchors having a
defined spin which specifies where the Y+ axis is located.
The way that BOSL2 positions objects can be understood by viewing the
anchor arrows as shown above, or you can remember these rules:
1. When attaching to the TOP or BOTTOM: the FRONT of the child points to the front if possible;  otherwise the TOP of the child points BACK.
2. When attaching to other faces, if possible the child's UP anchor will point UP; otherwise, the BACK of the child points up (so the FRONT is pointed down).  

To show how this works we use this prismoid where the blue arrow is
pointing to the front and the green arrow points up.  Also note that
the front left edge is the only right angle.  

```openscad-3D
include <BOSL2/std.scad>
color_this("orange")
prismoid([8,8],[6,6],shift=-[1,1],h=8) {
     attach(TOP,BOT) anchor_arrow(color=[0,1,0],s=12);
     attach(FWD,BOT) anchor_arrow(s=12);     
}
```

If we attach this to the TOP by the LEFT side then we get the result
below.  Notice how the green UP arrow is pointing back.

```openscad-3D
include <BOSL2/std.scad>
cube(30) attach(TOP,LEFT)
color_this("orange")
  prismoid([8,8],[6,6],shift=-[1,1],h=8) {
    attach(TOP,BOT) anchor_arrow(color=[0,1,0],s=12);
    attach(FWD,BOT) anchor_arrow(s=12);     
  }
```

If we attach to the RIGHT using the same LEFT side anchor on the
prismoid then we get the result below.  Note that the green UP anchor
is pointing UP, in accordance with rule 2 from above.  

```openscad-3D
include <BOSL2/std.scad>
cube(30) attach(RIGHT,LEFT)
color_this("orange")
  prismoid([8,8],[6,6],shift=-[1,1],h=8) {
    attach(TOP,BOT) anchor_arrow(color=[0,1,0],s=12);
    attach(FWD,BOT) anchor_arrow(s=12);     
  }
```

The green UP arrow can always be arranged to point up unless we attach
either the top or bottom to one of the cube's vertical faces.  Here we
attach the bottom so you can still see both arrows.  The blue FRONT
arrow on the object is pointing down, as expected based on rule 2.  

```openscad-3D
include <BOSL2/std.scad>
cube(30) attach(RIGHT,BOT)
color_this("orange")
  prismoid([8,8],[6,6],shift=-[1,1],h=8) {
    attach(TOP,BOT) anchor_arrow(color=[0,1,0],s=12);
    attach(FWD,BOT) anchor_arrow(s=12);     
  }
```

What do you do if the direction the child appears is not the direction
you need?  To address this issue `attach()` provides a `spin=`
parameter which spins the attached child around the axis defined by
the joined anchor vectors.  Here is the last example with a rotation
applied to bring the front anchor back to the front:

```openscad-3D
include <BOSL2/std.scad>
cube(30) attach(RIGHT,BOT,spin=-90)
color_this("orange")
  prismoid([8,8],[6,6],shift=-[1,1],h=8) {
    attach(TOP,BOT) anchor_arrow(color=[0,1,0],s=12);
    attach(FWD,BOT) anchor_arrow(s=12);     
  }
```

Be aware that specifying `spin=` to `attach()` is not equivalent to
using the `spin=` argument to the child.  Unlike `orient=` and
`anchor=`, which are ignored, the child `spin=` argument is still
respected, but it may be difficult to figure out which axis it will
rotate on.  It is more intuitive to ignore the child spin parameter
and only use the spin parameter to `attach()`.  The spin must be
scalar but need not be a multiple of 90 degrees.

```openscad-3D
include <BOSL2/std.scad>
cube(30) attach(RIGHT,BOT,spin=-37)
color_this("orange")
  prismoid([8,8],[6,6],shift=-[1,1],h=8) {
    attach(TOP,BOT) anchor_arrow(color=[0,1,0],s=12);
    attach(FWD,BOT) anchor_arrow(s=12);     
  }
```

By default, `attach()` places the child exactly flush with the surface
of the parent.  Sometimes it's useful to have the child overlap the
parent by translating it into the parent.  You can do this with the
`overlap=` argument to `attach()`.  A positive value will cause the
child to overlap the parent, and a negative value will move the child
away from the parent, leaving a small gap.  In the first example we use a very large value of
overlap so the cube is sunk deeply into the parent.  In the second
example a large negative overlap value raises the child high above the
parent.  

```openscad-3D
include <BOSL2/std.scad>
cuboid(50)
    attach(TOP,BOT,overlap=15)
        color("green")cuboid(20);
```

```openscad-3D
include <BOSL2/std.scad>
cube(50,center=true)
    attach(TOP,BOT,overlap=-20)
        cyl(d=20,h=20);
```

Another feature provided by the double argument form of `attach()` is
alignment, which works in a similar way to `align()`.  You can specify
`align=` to align the attached child to an edge or corner.  The
example below shows five different alignments.  

```openscad-3D;Big
include <BOSL2/std.scad>
module thing(){
  color_this("orange")
    prismoid([8,8],[6,6],shift=-[1,1],h=8) {
      attach(TOP,BOT) anchor_arrow(color=[0,1,0],s=12);
      attach(FWD,BOT) anchor_arrow(s=12);     
    }
}
prismoid([50,50],[35,35],h=25,anchor=BOT){
  attach(TOP,BOT,align=FRONT) thing();
  attach(RIGHT,BOT,align=BOT) thing();    
  attach(RIGHT,BACK,align=FRONT) thing();
  attach(FRONT,BACK,align=BOT,spin=45) thing();
  attach(TOP,RIGHT,align=RIGHT,spin=90) thing();
}
```

As with `align()` if you turn an object 90 degrees it can match up
with parallel edges, but if you turn it an arbitrary angle, a corner
of the child will contact the edge of the parent.  Also like align()
the anchor points of the parent and child are aligned but this does
not necessarily mean that edges line up neatly when the shapes have
varying angles.  This misalignment is visible in the object attached
at the RIGHT and aligned to the FRONT.

You may be wondering why all this fuss with align is necessary.
Couldn't you just attach an object at an anchor on an edge?  When you
do this, the object will be attached using the edge anchor, which is
not perpendicular to the faces of the object.  The example below shows
attachment to an edge anchor and also a corner anchor.  

```openscad-3D
include <BOSL2/std.scad>
cube(30)
   color("orange"){
     attach(RIGHT+FRONT,BOT) 
        prismoid([8,8],[6,6],shift=-[1,1],h=8);
     attach(TOP+LEFT+FWD,BOT)
        prismoid([8,8],[6,6],shift=-[1,1],h=8);
   }
```

When using the `align` option to `attach()` you can also set `inset`,
which works the same way as the `inset` parameter to `align()`.  It
shifts the child away from the edge or edges where it is aligned by
the specified amount.  

```openscad-3D
include <BOSL2/std.scad>
prismoid([50,50],[50,25],25){
  attach(FWD,BOT,align=TOP,inset=3) color("lavender")cuboid(5);
  attach(FWD,BOT,align=BOT+RIGHT,inset=3) color("purple")cuboid(5);
}
```

The last capability provided by `attach()` is to attach the child
**inside** the parent object.  This is useful if you want to subtract
the child from the parent.  Doing this requires using tagged
operations with `diff()` which is explained in more detail below. 
For the examples here, note that the `diff()` and `tag()` operations
that appear cause the child to be subtracted.  We return to the
example that started this section, with anchor arrows shown on the two
objects.  

```openscad-3D
include <BOSL2/std.scad>
cube(50,anchor=BOT) attach(TOP) anchor_arrow(30);
right(60)cylinder(d1=30,d2=15,h=25) attach(TOP) anchor_arrow(30);
```

Inside attachment is activated using `inside=true` and it lines up the
anchor arrows so they point together the **same** direction instead of
opposite directions like regular outside attachment.  The result in
this case is appears below, where we have cut away the front half to
show the interior: 

```openscad-3D
include <BOSL2/std.scad>
back_half(s=200)
diff()
cube(50,anchor=BOT)
  attach(TOP,TOP,inside=true)
    cylinder(d1=30,d2=15,h=25);
```

The top of the cavity has a thin layer on it, which occurs because the
two objects share a face in the difference.  To fix this you can use
the `shiftout` parameter to `attach()`.  In this case you could also
use a negative `overlay` value, but the `shiftout` parameter shifts
out in every direction that is needed, which may be three directions
if you align the child at a corner.  The above example looks like this
with with the shift added:

```openscad-3D
include <BOSL2/std.scad>
back_half(s=200)
diff()
cube(50,anchor=BOT)
  attach(TOP,TOP,inside=true,shiftout=0.01)
    cylinder(d1=30,d2=15,h=25);
```

Here is an example of connecting the same object on the right, but
this time with the BOTTOM anchor.  Note how the BOTTOM anchor is
aligned to the RIGHT so it is parallel and pointing in the same
direction as the RIGHT anchor.  

```openscad-3D
include <BOSL2/std.scad>
back_half(s=200)
diff()
cuboid(50)
  attach(RIGHT,BOT,inside=true,shiftout=0.01)
    cylinder(d1=30,d2=15,h=25);
```

Here is an example where alignment moves the object into the corner,
and we benefit from shiftout providing 3 dimensions of adjustment:

```openscad-3D
include <BOSL2/std.scad>
diff()
cuboid(10)
  attach(TOP,TOP,align=RIGHT+FWD,inside=true,shiftout=.01)
    cuboid([2,5,9]);
```

As with `position()`, with any use of `attach()` you can still apply your own translations and
other transformations even after attaching an object.  However, the
order of operations now matters.  If you apply a translation outside
of the anchor then it acts in the parent's global coordinate system, so the
child moves up in this example, where the light gray shows the
untranslated object.  

```openscad-3D
include <BOSL2/std.scad>
cuboid(50){
  %attach(RIGHT,BOT)
    cyl(d1=30,d2=15,h=25);
  up(13)
    color("green") attach(RIGHT,BOT)
      cyl(d1=30,d2=15,h=25);
}
```

On the other hand, if you put the translation between the attach and
the object in your code, then it will act in the local coordinate system of
the parent at the parent's anchor, so in the example below it moves to the right.  

```openscad-3D
include <BOSL2/std.scad>
cuboid(50){
  %attach(RIGHT,BOT)
    cyl(d1=30,d2=15,h=25);
  color("green") attach(RIGHT,BOT)
    up(13)
      cyl(d1=30,d2=15,h=25);
}
```

Parent-child Anchor attachment with CENTER anchors can be surprising because the anchors
both point upwards, so in the example below, the child's CENTER anchor
points up, so it is inverted when it is attached to the parent cone.
Note that the anchors are CENTER anchors, so the bases of the anchors are
hidden in the middle of the objects.  

```openscad-3D
include <BOSL2/std.scad>
cylinder(d1=30,d2=15,h=25) attach(CENTER) anchor_arrow(40);
right(40)cylinder(d1=30,d2=15,h=25) attach(CENTER) anchor_arrow(40);
```

```openscad-3D
include <BOSL2/std.scad>
cylinder(d1=30,d2=15,h=25)
    attach(CENTER,CENTER)
        cylinder(d1=30,d2=15,h=25);
```

Is is also possible to attach to edges and corners of the parent
object.  The anchors for edges spin the child so its BACK direction is
aligned with the edge.  If the edge belongs to a top or bottom
horizontal face, then the BACK directions will point clockwise around
the face, as seen from outside the shape.  (This is the same direction
required for construction of valid faces in OpenSCAD.)  Otherwise, the
BACK direction will point upwards.

Examine the red flags below, where only edge anchors appear on a
prismoid.  The top face shows the red flags pointing clockwise.
The sloped side edges point along the edges, generally upward, and
the bottom ones appear to point counter-clockwise, but if we viewed
the shape from the bottom they would also appear clockwise.  

```openscad-3D;Big
include <BOSL2/std.scad>
prismoid([100,175],[55,88], h=55)
  for(i=[-1:1], j=[-1:1], k=[-1:1])
    let(anchor=[i,j,k])
       if (sum(v_abs(anchor))==2)
         attach(anchor,BOT)anchor_arrow(40);
```

In this example cylinders sink half-way into the top edges of the
prismoid:

```openscad-3D;Big
include <BOSL2/std.scad>
$fn=16;
r=6;
prismoid([100,175],[55,88], h=55){
   attach([TOP+RIGHT,TOP+LEFT],LEFT,overlap=r/2) cyl(r=r,l=88+2*r,rounding=r);
   attach([TOP+FWD,TOP+BACK],LEFT,overlap=r/2) cyl(r=r,l=55+2*r, rounding=r);   
}
```

This type of edge attachment is useful for attaching 3d edge masks to
edges:

```openscad-3D;Big
include <BOSL2/std.scad>
$fn=32;
diff()
cuboid(75)
   attach([FRONT+LEFT, FRONT+RIGHT, BACK+LEFT, BACK+RIGHT],
          FWD+LEFT,inside=true)
     rounding_edge_mask(l=76, r1=8,r2=28);
```

## Parent Anchor Attachment (Single Argument Attachment)

The second form of attachment is parent anchor attachment, which just
uses a single argument.  This form of attachment is less useful in
general and does not provide alignment.  When you give `attach()` a parent anchor but no child anchor it
orients the child according to the parent anchor direction but then
simply places the child based on its internally defined anchor at the
parent anchor position.  For most objects the default anchor is the
CENTER anchor, so objects will appear sunk half-way into the parent.

```openscad-3D
include <BOSL2/std.scad>
cuboid(30)
    attach(TOP)
        color("green")cuboid(10);
```

Some objects such as `cylinder()`, `prismoid()`, and `anchor_arrow()` have default anchors on the bottom, so they will appear
on the surface.  For objects like this you can save a little bit of
typing by using parent anchor attachment.  But in the case of `cube()`
the anchor is not centered, so the result is:

```openscad-3D
include <BOSL2/std.scad>
cube(30)
    attach(TOP)
        color("green")cube(10);
```

In order to make single argument attachment produce the results you
need you will probably need to change the child anchor.  Note that unlike
parent-child anchor attachment, **with parent anchor attachment the `anchor=` and `orient=` arguments
are respected.**  We could therefore place a cuboid like this:

```openscad-3D
include <BOSL2/std.scad>
cuboid(30)
  attach(RIGHT)
      color("green")cuboid(10,anchor=BOT);
```

If you need to place a cuboid at the anchor point but need it anchored
relative to one of the bottom edge or corner anchors then you can do
that with parent anchor attachment:

```openscad-3D
include <BOSL2/std.scad>
cuboid(30)
  attach(RIGHT)
      color("green")cuboid(10,anchor=BOT+FWD);
```

Another case where single argument attachment is useful is when the
child doesn't have proper attachment support.
If you use double argument attachment in such cases the results will
be incorrect because the child doesn't properly respond to the
internally propagated anchor directives.  With single argument
attachment, this is not a problem: the origin
of the child will be placed at the parent anchor point.  One module
without attachment support is `linear_extrude()`.  

```openscad-3D
include <BOSL2/std.scad>
cuboid(20)
  attach(RIGHT)
     color("red")linear_extrude(height=2) star(n=7,ir=3,or=7);
```

As noted earlier, you can set `orient=` for children with parent
anchor attachment, though the behavior may not be intuitive because
the attachment process transforms the coordinate system and the
orientation is done in the attached coordinate system.  It may be
helpful to start with the object attached to TOP and recall the rules
from the previous section about how orientation works.  The same rules
apply here.  Note that the forward arrow is pointing down after
attaching the object on the RIGHT face.

```openscad-3D
include <BOSL2/std.scad>
cuboid(20){
  attach(RIGHT)
     color_this("red")cuboid([2,4,8],orient=RIGHT,anchor=RIGHT)
        attach(FWD) anchor_arrow();
  attach(TOP)
     color_this("red")cuboid([2,4,8],orient=RIGHT,anchor=RIGHT)
            attach(FWD) anchor_arrow();
}
```

## Positioning and Attaching Multiple Children

You can attach or position more than one child at a time by enclosing them all in braces:

```openscad-3D
include <BOSL2/std.scad>
cube(50, center=true) {
    attach(TOP) cylinder(d1=50,d2=20,h=20);
    position(RIGHT) cylinder(d1=50,d2=20,h=20);
}
```

If you want to attach the same shape to multiple places on the same parent, you can pass the
desired anchors as a list to the `attach()` or `position()` modules:

```openscad-3D
include <BOSL2/std.scad>
cube(50, center=true)
    attach([RIGHT,FRONT],TOP) cylinder(d1=35,d2=20,h=25);
```

```openscad-3D
include <BOSL2/std.scad>
cube(50, center=true)
    position([TOP,RIGHT,FRONT]) cylinder(d1=35,d2=20,h=25);
```

## Attaching 2D Children
You can use attachments in 2D as well.  As usual for the 2D case you
can use TOP and BOTTOM as alternative to BACK and FORWARD.  With
parent-child anchor attachment you cannot use the spin parameter to
`attach()` nor can you specify spin to the child.  Spinning the child
on the Z axis would rotate the anchor arrows out of alignment.  

```openscad-2D
include <BOSL2/std.scad>
rect(50){
    attach(RIGHT,FRONT)
        color("red")trapezoid(w1=30,w2=0,h=30);
    attach(LEFT,FRONT,align=[FRONT,BACK],inset=3)
        color("green") trapezoid(w1=25, w2=0,h=30);
}
```

```openscad-2D
include <BOSL2/std.scad>
diff()
circle(d=50){
    attach(TOP,BOT,overlap=5)
        trapezoid(w1=30,w2=0,h=30);
    attach(BOT,BOT,inside=true)
        tag("remove")
        trapezoid(w1=30,w2=0,h=30);
}        
```

## Tagged Operations
BOSL2 introduces the concept of tags.  Tags are names that can be given to attachables, so that
you can refer to them when performing `diff()`, `intersect()`, and `conv_hull()` operations.
Each object can have no more than one tag at a time.  

### `diff([remove], [keep])`
The `diff()` operator is used to difference away all shapes marked with the tag(s) given to
`remove`, from the other shapes.  

For example, to difference away a child cylinder from the middle of a parent cube, you can
do this:

```openscad-3D
include <BOSL2/std.scad>
diff("hole")
cube(100, center=true)
    tag("hole")cylinder(h=101, d=50, center=true);
```

The `keep=` argument takes tags for shapes that you want to keep in the output.

```openscad-3D
include <BOSL2/std.scad>
diff("dish", keep="antenna")
cube(100, center=true)
    attach([FRONT,TOP], overlap=33) {
        tag("dish") cylinder(h=33.1, d1=0, d2=95);
        tag("antenna") cylinder(h=33.1, d=10);
    }
```

Remember that tags applied with `tag()` are inherited by children.  In this case, we need to explicitly
untag the first cylinder (or change its tag to something else), or it
will inherit the "keep" tag and get kept.  

```openscad-3D
include <BOSL2/std.scad>
diff("hole", "keep")
tag("keep")cube(100, center=true)
    attach([RIGHT,TOP]) {
        tag("") cylinder(d=95, h=5);
        tag("hole") cylinder(d=50, h=11, anchor=CTR);
    }
```

You can apply a tag that is not propagated to the children using
`tag_this()`.  The above example could then be redone:

diff("hole", "keep")
tag_this("keep")cube(100, center=true)
    attach([RIGHT,TOP]) {
        cylinder(d=95, h=5);
        tag("hole") cylinder(d=50, h=11, anchor=CTR);
    }

You can of course apply `tag()` to several children.

```openscad-3D
include <BOSL2/std.scad>
diff("hole")
cube(100, center=true)
    attach([FRONT,TOP], overlap=20)
        tag("hole") {
            cylinder(h=20.1, d1=0, d2=95);
            down(10) cylinder(h=30, d=30);
        }
```

Many of the modules that use tags have default values for their tags.  For diff the default
remove tag is "remove" and the default keep tag is "keep".  In this example we rely on the
default values:

```openscad-3D
include <BOSL2/std.scad>
diff()
sphere(d=100) {
    tag("keep")xcyl(d=40, l=120);
    tag("remove")cuboid([40,120,100]);
}
```

The parent object can be differenced away from other shapes.  Tags are inherited by children,
though, so you will need to set the tags of the children as well as the parent.

```openscad-3D
include <BOSL2/std.scad>
diff("hole")
tag("hole")cube([20,11,45], center=true)
    tag("body")cube([40,10,90], center=true);
```

Tags (and therefore tag-based operations like `diff()`) only work correctly with attachable
children.  However, a number of built-in modules for making shapes are *not* attachable.
Some notable non-attachable modules are `text()`, `linear_extrude()`, `rotate_extrude()`,
`polygon()`, `polyhedron()`, `import()`, `surface()`, `union()`, `difference()`,
`intersection()`, `offset()`, `hull()`, and `minkowski()`.

To allow you to use tags-based operations with non-attachable shapes, you can wrap them with the
`force_tag()` module to specify their tags.  For example:

```openscad-3D
include <BOSL2/std.scad>
diff("hole")
cuboid(50)
  attach(TOP)
    force_tag("hole")
      rotate_extrude()
        right(15)
          square(10,center=true);
```

### `intersect([intersect], [keep])`

To perform an intersection of attachables, you can use the `intersect()` module.  This is
specifically intended to address the situation where you want intersections involving a parent
and a child, something that is impossible with the native `intersection()` module.  This module
treats the children in three groups: objects matching the `intersect` tags, objects matching
the tags listed in `keep` and the remaining objects that don't match any listed tags.  The
intersection is computed between the union of the `intersect` tagged objects and the union of
the objects that don't match any listed tags.  Finally the objects listed in `keep` are union
ed with the result.  

In this example the parent (untagged) is intersected with a conical
bounding shape, which is tagged with the intersect tag.

```openscad-3D
include <BOSL2/std.scad>
intersect("bounds")
cube(100, center=true)
    tag("bounds") cylinder(h=100, d1=120, d2=95, center=true, $fn=72);
```

In this example the child objects are intersected with the bounding box parent.  

```openscad-3D
include <BOSL2/std.scad>
intersect("pole cap")
cube(100, center=true)
    attach([TOP,RIGHT]) {
        tag("pole")cube([40,40,80],center=true);
        tag("cap")sphere(d=40*sqrt(2));
    }
```

The default `intersect` tag is "intersect" and the default `keep` tag is "keep".  Here is an
example where "keep" is used to keep the pole from being removed by the intersection. 

```openscad-3D
include <BOSL2/std.scad>
intersect()
cube(100, center=true) {
    tag("intersect")cylinder(h=100, d1=120, d2=95, center=true, $fn=72);
    tag("keep")zrot(45) xcyl(h=140, d=20, $fn=36);
}
```

### `conv_hull([keep])`
You can use the `conv_hull()` module to hull shapes together.  Objects
marked with the keep tags are excluded from the hull and unioned into the final result.
The default keep tag is "keep".  

```openscad-3D
include <BOSL2/std.scad>
conv_hull()
cube(50, center=true) {
    cyl(h=100, d=20);
    tag("keep")xcyl(h=100, d=20);
}
```

## 3D Masking Attachments
To make it easier to mask away shapes from various edges of an attachable parent shape, there
are a few specialized alternatives to the `attach()` and `position()` modules.

### `edge_mask()`
If you have a 3D mask shape that you want to difference away from various edges, you can use
the `edge_mask()` module.  This module will take a vertically oriented shape, and will rotate
and move it such that the BACK, RIGHT (X+,Y+) side of the shape will be aligned with the given
edges.  The shape will be tagged as a "remove" so that you can use
`diff()` with its default "remove" tag.  For example,
here's a shape for rounding an edge:

```openscad-3D
include <BOSL2/std.scad>
module round_edge(l,r) difference() {
    translate([-1,-1,-l/2])
        cube([r+1,r+1,l]);
    translate([r,r])
        cylinder(h=l+1,r=r,center=true, $fn=quantup(segs(r),4));
}
round_edge(l=30, r=19);
```

You can use that mask to round various edges of a cube:

```openscad-3D
include <BOSL2/std.scad>
module round_edge(l,r) difference() {
    translate([-1,-1,-l/2])
        cube([r+1,r+1,l]);
    translate([r,r])
        cylinder(h=l+1,r=r,center=true, $fn=quantup(segs(r),4));
}
diff()
cube([50,60,70],center=true)
    edge_mask([TOP,"Z"],except=[BACK,TOP+LEFT])
        round_edge(l=71,r=10);
```

### `corner_mask()`
If you have a 3D mask shape that you want to difference away from various corners, you can use
the `corner_mask()` module.  This module will take a shape and rotate and move it such that the
BACK RIGHT TOP (X+,Y+,Z+) side of the shape will be aligned with the given corner.  The shape
will be tagged as a "remove" so that you can use `diff()` with its
default "remove" tag.  For example, here's a shape for
rounding a corner:

```openscad-3D
include <BOSL2/std.scad>
module round_corner(r) difference() {
    translate(-[1,1,1])
        cube(r+1);
    translate([r,r,r])
        spheroid(r=r, style="aligned", $fn=quantup(segs(r),4));
}
round_corner(r=10);
```

You can use that mask to round various corners of a cube:

```openscad-3D
include <BOSL2/std.scad>
module round_corner(r) difference() {
    translate(-[1,1,1])
        cube(r+1);
    translate([r,r,r])
        spheroid(r=r, style="aligned", $fn=quantup(segs(r),4));
}
diff()
cube([50,60,70],center=true)
    corner_mask([TOP,FRONT],LEFT+FRONT+TOP)
        round_corner(r=10);
```

### Mix and Match Masks
You can use `edge_mask()` and `corner_mask()` together as well:

```openscad-3D
include <BOSL2/std.scad>
module round_corner(r) difference() {
    translate(-[1,1,1])
        cube(r+1);
    translate([r,r,r])
        spheroid(r=r, style="aligned", $fn=quantup(segs(r),4));
}
module round_edge(l,r) difference() {
    translate([-1,-1,-l/2])
        cube([r+1,r+1,l]);
    translate([r,r])
        cylinder(h=l+1,r=r,center=true, $fn=quantup(segs(r),4));
}
diff()
cube([50,60,70],center=true) {
    edge_mask("ALL") round_edge(l=71,r=10);
    corner_mask("ALL") round_corner(r=10);
}
```

## 2D Profile Mask Attachments
While 3D mask shapes give you a great deal of control, you need to make sure they are correctly
sized, and you need to provide separate mask shapes for corners and edges.  Often, a single 2D
profile could be used to describe the edge mask shape (via `linear_extrude()`), and the corner
mask shape (via `rotate_extrude()`).  This is where `edge_profile()`, `corner_profile()`, and
`face_profile()` come in.

### `edge_profile()`
Using the `edge_profile()` module, you can provide a 2D profile shape and it will be linearly
extruded to a mask of the appropriate length for each given edge.  The resultant mask will be
tagged with "remove" so that you can difference it away with `diff()`
with the default "remove" tag.  The 2D profile is
assumed to be oriented with the BACK, RIGHT (X+,Y+) quadrant as the "cutter edge" that gets
re-oriented towards the edges of the parent shape.  A typical mask profile for chamfering an
edge may look like:

```openscad-2D
include <BOSL2/std.scad>
mask2d_roundover(10);
```

Using that mask profile, you can mask the edges of a cube like:

```openscad-3D
include <BOSL2/std.scad>
diff()
cube([50,60,70],center=true)
   edge_profile("ALL")
       mask2d_roundover(10);
```

### `corner_profile()`
You can use the same profile to make a rounded corner mask as well:

```openscad-3D
include <BOSL2/std.scad>
diff()
cube([50,60,70],center=true)
   corner_profile("ALL", r=10)
       mask2d_roundover(10);
```

### `face_profile()`
As a simple shortcut to apply a profile mask to all edges and corners of a face, you can use the
`face_profile()` module:

```openscad-3D
include <BOSL2/std.scad>
diff()
cube([50,60,70],center=true)
   face_profile(TOP, r=10)
       mask2d_roundover(10);
```

## Coloring Attachables
Usually, when coloring a shape with the `color()` module, the parent color overrides the colors of
all children.  This is often not what you want:

```openscad-3D
include <BOSL2/std.scad>
$fn = 24;
color("red") spheroid(d=3) {
    attach(CENTER,BOT) color("white") cyl(h=10, d=1) {
        attach(TOP,BOT) color("green") cyl(h=5, d1=3, d2=0);
    }
}
```

If you use the `recolor()` module, however, the child's color
overrides the color of the parent.  This is probably easier to understand by example:

```openscad-3D
include <BOSL2/std.scad>
$fn = 24;
recolor("red") spheroid(d=3) {
    attach(CENTER,BOT) recolor("white") cyl(h=10, d=1) {
        attach(TOP,BOT) recolor("green") cyl(h=5, d1=3, d2=0);
    }
}
```

Be aware that `recolor()` will only work if you avoid using the native
`color()` module.  Also note that `recolor()` still affects all its
children.  If you want to color an object without affecting the
children you can use `color_this()`.  See the difference below:

```openscad-3D
include <BOSL2/std.scad>
$fn = 24;
recolor("red") spheroid(d=3) {
    attach(CENTER,BOT) recolor("white") cyl(h=10, d=1) {
        attach(TOP,BOT)  cyl(h=5, d1=3, d2=0);
    }
}
right(5)
recolor("red") spheroid(d=3) {
    attach(CENTER,BOT) color_this("white") cyl(h=10, d=1) {
        attach(TOP,BOT)  cyl(h=5, d1=3, d2=0);
    }
}
```

As with all of the attachable features, these color modules only work
on attachable objects, so they will have no effect on objects you
create using `linear_extrude()` or `rotate_extrude()`.  

## Making Attachables
To make a shape attachable, you just need to wrap it with an `attachable()` module with a
basic description of the shape's geometry.  By default, the shape is expected to be centered
at the origin.  The `attachable()` module expects exactly two children.  The first will be
the shape to make attachable, and the second will be `children()`,
literally.

### Pass-through Attachables
The simplest way to make your own attachable module is to simply pass
through to a pre-existing attachable submodule.  This could be
appropriate if you want to rename a module, or if the anchors of an
existing module are suited to (or good enough for) your object.  In
order for your attachable module to work properly you need to accept
the `anchor`, `spin` and `orient` parameters, give them suitable
defaults, and pass them to the attachable submodule.  Don't forget to
pass the children to the attachable submodule as well, or your new
module will ignore its children.  

```openscad-3D
include <BOSL2/std.scad>
$fn=32;
module cutcube(anchor=CENTER,spin=0,orient=UP)
{
   tag_scope(){
     diff()
       cuboid(15, rounding=2, anchor=anchor,spin=spin,orient=orient){
         tag("remove")attach(TOP)cuboid(5);
         children();
       }
   }
}
diff()
cutcube()
  tag("remove")attach(RIGHT) cyl(d=2,h=8);
```

### Prismoidal/Cuboidal Attachables
To make a cuboidal or prismoidal shape attachable, you use the `size`, `size2`, and `offset`
arguments of `attachable()`.

In the most basic form, where the shape is fully cuboid, with top and bottom of the same size,
and directly over one another, you can just use `size=`.

```openscad-3D;Big
include <BOSL2/std.scad>
module cubic_barbell(s=100, anchor=CENTER, spin=0, orient=UP) {
    attachable(anchor,spin,orient, size=[s*3,s,s]) {
        union() {
            xcopies(2*s) cube(s, center=true);
            xcyl(h=2*s, d=s/4);
        }
        children();
    }
}
cubic_barbell(100) show_anchors(60);
```

When the shape is prismoidal, where the top is a different size from the bottom, you can use
the `size2=` argument as well. While `size=` takes all three axes sizes, the `size2=` argument
only takes the [X,Y] sizes of the top of the shape.

```openscad-3D;Big
include <BOSL2/std.scad>
module prismoidal(size=[100,100,100], scale=0.5, anchor=CENTER, spin=0, orient=UP) {
    attachable(anchor,spin,orient, size=size, size2=[size.x, size.y]*scale) {
        hull() {
            up(size.z/2-0.005)
                linear_extrude(height=0.01, center=true)
                    square([size.x,size.y]*scale, center=true);
            down(size.z/2-0.005)
                linear_extrude(height=0.01, center=true)
                    square([size.x,size.y], center=true);
        }
        children();
    }
}
prismoidal([100,60,30], scale=0.5) show_anchors(20);
```

When the top of the prismoid can be shifted away from directly above the bottom, you can use
the `shift=` argument.  The `shift=` argument takes an [X,Y] vector of the offset of the center
of the top from the XY center of the bottom of the shape.

```openscad-3D;Big
include <BOSL2/std.scad>
module prismoidal(size=[100,100,100], scale=0.5, shift=[0,0], anchor=CENTER, spin=0, orient=UP) {
    attachable(anchor,spin,orient, size=size, size2=[size.x, size.y]*scale, shift=shift) {
        hull() {
            translate([shift.x, shift.y, size.z/2-0.005])
                linear_extrude(height=0.01, center=true)
                    square([size.x,size.y]*scale, center=true);
            down(size.z/2-0.005)
                linear_extrude(height=0.01, center=true)
                    square([size.x,size.y], center=true);
        }
        children();
    }
}
prismoidal([100,60,30], scale=0.5, shift=[-30,20]) show_anchors(20);
```

In the case that the prismoid is not oriented vertically, (ie, where the `shift=` or `size2=`
arguments should refer to a plane other than XY) you can use the `axis=` argument.  This lets
you make prismoids naturally oriented forwards/backwards or sideways.

```openscad-3D;Big
include <BOSL2/std.scad>
module yprismoidal(
    size=[100,100,100], scale=0.5, shift=[0,0],
    anchor=CENTER, spin=0, orient=UP
) {
    attachable(
        anchor, spin, orient,
        size=size, size2=point2d(size)*scale,
        shift=shift, axis=BACK
    ) {
        xrot(-90) hull() {
            translate([shift.x, shift.y, size.z/2-0.005])
                linear_extrude(height=0.01, center=true)
                    square([size.x,size.y]*scale, center=true);
            down(size.z/2-0.005)
                linear_extrude(height=0.01, center=true)
                    square([size.x,size.y], center=true);
        }
        children();
    }
}
yprismoidal([100,60,30], scale=1.5, shift=[20,20]) show_anchors(20);
```

### Cylindrical Attachables
To make a cylindrical shape attachable, you use the `l`, and `r`/`d`, args of `attachable()`.

```openscad-3D;Big
include <BOSL2/std.scad>
module twistar(l,r,d, anchor=CENTER, spin=0, orient=UP) {
    r = get_radius(r=r,d=d,dflt=1);
    attachable(anchor,spin,orient, r=r, l=l) {
        linear_extrude(height=l, twist=90, slices=20, center=true, convexity=4)
            star(n=20, r=r, ir=r*0.9);
        children();
    }
}
twistar(l=100, r=40) show_anchors(20);
```

If the cylinder is elipsoidal in shape, you can pass the unequal X/Y sizes as a 2-item vector
to the `r=` or `d=` argument.

```openscad-3D
include <BOSL2/std.scad>
module ovalstar(l,rx,ry, anchor=CENTER, spin=0, orient=UP) {
    attachable(anchor,spin,orient, r=[rx,ry], l=l) {
        linear_extrude(height=l, center=true, convexity=4)
            scale([1,ry/rx,1])
                star(n=20, r=rx, ir=rx*0.9);
        children();
    }
}
ovalstar(l=100, rx=50, ry=30) show_anchors(20);
```

For cylindrical shapes that aren't oriented vertically, use the `axis=` argument.

```openscad-3D
include <BOSL2/std.scad>
module ytwistar(l,r,d, anchor=CENTER, spin=0, orient=UP) {
    r = get_radius(r=r,d=d,dflt=1);
    attachable(anchor,spin,orient, r=r, l=l, axis=BACK) {
        xrot(-90)
            linear_extrude(height=l, twist=90, slices=20, center=true, convexity=4)
                star(n=20, r=r, ir=r*0.9);
        children();
    }
}
ytwistar(l=100, r=40) show_anchors(20);
```

### Conical Attachables
To make a conical shape attachable, you use the `l`, `r1`/`d1`, and `r2`/`d2`, args of
`attachable()`.

```openscad-3D;Big
include <BOSL2/std.scad>
module twistar(l, r,r1,r2, d,d1,d2, anchor=CENTER, spin=0, orient=UP) {
    r1 = get_radius(r1=r1,r=r,d1=d1,d=d,dflt=1);
    r2 = get_radius(r1=r2,r=r,d1=d2,d=d,dflt=1);
    attachable(anchor,spin,orient, r1=r1, r2=r2, l=l) {
        linear_extrude(height=l, twist=90, scale=r2/r1, slices=20, center=true, convexity=4)
            star(n=20, r=r1, ir=r1*0.9);
        children();
    }
}
twistar(l=100, r1=40, r2=20) show_anchors(20);
```

If the cone is ellipsoidal in shape, you can pass the unequal X/Y sizes as a 2-item vectors
to the `r1=`/`r2=` or `d1=`/`d2=` arguments.

```openscad-3D;Big
include <BOSL2/std.scad>
module ovalish(l,rx1,ry1,rx2,ry2, anchor=CENTER, spin=0, orient=UP) {
    attachable(anchor,spin,orient, r1=[rx1,ry1], r2=[rx2,ry2], l=l) {
        hull() {
            up(l/2-0.005)
                linear_extrude(height=0.01, center=true)
                    ellipse([rx2,ry2]);
            down(l/2-0.005)
                linear_extrude(height=0.01, center=true)
                    ellipse([rx1,ry1]);
        }
        children();
    }
}
ovalish(l=100, rx1=50, ry1=30, rx2=30, ry2=50) show_anchors(20);
```

For conical shapes that are not oriented vertically, use the `axis=` argument to indicate the
direction of the primary shape axis:

```openscad-3D;Big
include <BOSL2/std.scad>
module ytwistar(l, r,r1,r2, d,d1,d2, anchor=CENTER, spin=0, orient=UP) {
    r1 = get_radius(r1=r1,r=r,d1=d1,d=d,dflt=1);
    r2 = get_radius(r1=r2,r=r,d1=d2,d=d,dflt=1);
    attachable(anchor,spin,orient, r1=r1, r2=r2, l=l, axis=BACK) {
        xrot(-90)
            linear_extrude(height=l, twist=90, scale=r2/r1, slices=20, center=true, convexity=4)
                star(n=20, r=r1, ir=r1*0.9);
        children();
    }
}
ytwistar(l=100, r1=40, r2=20) show_anchors(20);
```

### Spherical Attachables
To make a spherical shape attachable, you use the `r`/`d` args of `attachable()`.

```openscad-3D;Big
include <BOSL2/std.scad>
module spikeball(r, d, anchor=CENTER, spin=0, orient=UP) {
    r = get_radius(r=r,d=d,dflt=1);
    attachable(anchor,spin,orient, r=r*1.1) {
        union() {
            sphere_copies(r=r, n=512, cone_ang=180) cylinder(r1=r/10, r2=0, h=r/10);
            sphere(r=r);
        }
        children();
    }
}
spikeball(r=50) show_anchors(20);
```

If the shape is an ellipsoid, you can pass a 3-item vector of sizes to `r=` or `d=`.

```openscad-3D
include <BOSL2/std.scad>
module spikeball(r, d, scale, anchor=CENTER, spin=0, orient=UP) {
    r = get_radius(r=r,d=d,dflt=1);
    attachable(anchor,spin,orient, r=r*1.1*scale) {
        union() {
            sphere_copies(r=r, n=512, scale=scale, cone_ang=180) cylinder(r1=r/10, r2=0, h=r/10);
            scale(scale) sphere(r=r);
        }
        children();
    }
}
spikeball(r=50, scale=[0.75,1,1.5]) show_anchors(20);
```

### VNF Attachables
If the shape just doesn't fit into any of the above categories, and you constructed it as a
[VNF](vnf.scad), you can use the VNF itself to describe the geometry with the `vnf=` argument.

There are two variations to how anchoring can work for VNFs. When `extent=true`, (the default)
then a plane is projected out from the origin, perpendicularly in the direction of the anchor,
to the furthest distance that intersects with the VNF shape.  The anchor point is then the
center of the points that still intersect that plane.

```openscad-FlatSpin,VPD=500
include <BOSL2/std.scad>
module stellate_cube(s=100, anchor=CENTER, spin=0, orient=UP) {
    s2 = 3 * s;
    verts = [
        [0,0,-s2*sqrt(2)/2],
        each down(s/2, p=path3d(square(s,center=true))),
        each zrot(45, p=path3d(square(s2,center=true))),
        each up(s/2, p=path3d(square(s,center=true))),
        [0,0,s2*sqrt(2)/2]
    ];
    faces = [
        [0,2,1], [0,3,2], [0,4,3], [0,1,4],
        [1,2,6], [1,6,9], [6,10,9], [2,10,6],
        [1,5,4], [1,9,5], [9,12,5], [5,12,4],
        [4,8,3], [4,12,8], [12,11,8], [11,3,8],
        [2,3,7], [3,11,7], [7,11,10], [2,7,10],
        [9,10,13], [10,11,13], [11,12,13], [12,9,13]
    ];
    vnf = [verts, faces];
    attachable(anchor,spin,orient, vnf=vnf) {
        vnf_polyhedron(vnf);
        children();
    }
}
stellate_cube(25) {
    attach(UP+RIGHT) {
        anchor_arrow(20);
        %cube([100,100,0.1],center=true);
    }
}
```

When `extent=false`, then the anchor point will be the furthest intersection of the VNF with
the anchor ray from the origin. The orientation of the anchor point will be the normal of the
face at the intersection.  If the intersection is at an edge or corner, then the orientation
will bisect the angles between the faces.

```openscad-VPD=1250
include <BOSL2/std.scad>
module stellate_cube(s=100, anchor=CENTER, spin=0, orient=UP) {
    s2 = 3 * s;
    verts = [
        [0,0,-s2*sqrt(2)/2],
        each down(s/2, p=path3d(square(s,center=true))),
        each zrot(45, p=path3d(square(s2,center=true))),
        each up(s/2, p=path3d(square(s,center=true))),
        [0,0,s2*sqrt(2)/2]
    ];
    faces = [
        [0,2,1], [0,3,2], [0,4,3], [0,1,4],
        [1,2,6], [1,6,9], [6,10,9], [2,10,6],
        [1,5,4], [1,9,5], [9,12,5], [5,12,4],
        [4,8,3], [4,12,8], [12,11,8], [11,3,8],
        [2,3,7], [3,11,7], [7,11,10], [2,7,10],
        [9,10,13], [10,11,13], [11,12,13], [12,9,13]
    ];
    vnf = [verts, faces];
    attachable(anchor,spin,orient, vnf=vnf, extent=false) {
        vnf_polyhedron(vnf);
        children();
    }
}
stellate_cube() show_anchors(50);
```

```openscad-3D
include <BOSL2/std.scad>
$fn=32;
R = difference(circle(10), right(2, circle(9)));
linear_sweep(R,height=10,atype="hull")
    attach(RIGHT) anchor_arrow();
```

## Making Named Anchors
While vector anchors are often useful, sometimes there are logically extra attachment points that
aren't on the perimeter of the shape.  This is what named string anchors are for.  For example,
the `teardrop()` shape uses a cylindrical geometry for it's vector anchors, but it also provides
a named anchor "cap" that is at the tip of the hat of the teardrop shape.

Named anchors are passed as an array of `named_anchor()`s to the `anchors=` argument of `attachable()`.
The `named_anchor()` call takes a name string, a positional point, an orientation vector, and a spin.
The name is the name of the anchor.  The positional point is where the anchor point is at.  The
orientation vector is the direction that a child attached at that anchor point should be oriented.
The spin is the number of degrees that an attached child should be rotated counter-clockwise around
the orientation vector.  Spin is optional, and defaults to 0.

To make a simple attachable shape similar to a `teardrop()` that provides a "cap" anchor, you may
define it like this:

```openscad-3D
include <BOSL2/std.scad>
module raindrop(r, thick, anchor=CENTER, spin=0, orient=UP) {
    anchors = [
        named_anchor("cap", [0,r/sin(45),0], BACK, 0)
    ];
    attachable(anchor,spin,orient, r=r, l=thick, anchors=anchors) {
        linear_extrude(height=thick, center=true) {
            circle(r=r);
            back(r*sin(45)) zrot(45) square(r, center=true);
        }
        children();
    }
}
raindrop(r=25, thick=20, anchor="cap");
```

If you want multiple named anchors, just add them to the list of anchors:

```openscad-FlatSpin,VPD=150
include <BOSL2/std.scad>
module raindrop(r, thick, anchor=CENTER, spin=0, orient=UP) {
    anchors = [
        named_anchor("captop", [0,r/sin(45), thick/2], BACK+UP,   0),
        named_anchor("cap",    [0,r/sin(45), 0      ], BACK,      0),
        named_anchor("capbot", [0,r/sin(45),-thick/2], BACK+DOWN, 0)
    ];
    attachable(anchor,spin,orient, r=r, l=thick, anchors=anchors) {
        linear_extrude(height=thick, center=true) {
            circle(r=r);
            back(r*sin(45)) zrot(45) square(r, center=true);
        }
        children();
    }
}
raindrop(r=15, thick=10) show_anchors();
```

Sometimes the named anchor you want to add may be at a point that is reached through a complicated
set of translations and rotations.  One quick way to calculate that point is to reproduce those
transformations in a transformation matrix chain.  This is simplified by how you can use the
function forms of almost all the transformation modules to get the transformation matrices, and
chain them together with matrix multiplication.  For example, if you have:

```
scale([1.1, 1.2, 1.3]) xrot(15) zrot(25) right(20) sphere(d=1);
```

and you want to calculate the center point of the sphere, you can do it like:

```
sphere_pt = apply(
    scale([1.1, 1.2, 1.3]) * xrot(15) * zrot(25) * right(20),
    [0,0,0]
);
```

## Overriding Standard Anchors

Sometimes you may want to use the standard anchors but override some
of them.  Returning to the square barebell example above, the anchors
at the right and left sides are on the cubes at each end, but the
anchors at x=0 are in floating in space.  For prismoidal/cubic anchors
in 3D and trapezoidal/rectangular anchors in 2D we can override a single anchor by
specifying the override option and giving the anchor that is being
overridden, and then the replacement in the form
`[position, direction, spin]`.  Most often you will only want to
override the position.  If you omit the other list items then the
value drived from the standard anchor will be used. Below we override
position of the FWD anchor:

```openscad-3D;Big
include<BOSL2/std.scad>
module cubic_barbell(s=100, anchor=CENTER, spin=0, orient=UP) {
    override = [
                 [FWD,  [[0,-s/8,0]]]
               ];
    attachable(anchor,spin,orient, size=[s*3,s,s],override=override) {
        union() {
            xcopies(2*s) cube(s, center=true);
            xcyl(h=2*s, d=s/4);
        }
        children();
    }
}
cubic_barbell(100) show_anchors(60);
```

Note how the FWD anchor is now rooted on the cylindrical portion.  If
you wanted to also change its direction and spin you could do it like
this:

```openscad-3D;Big
include<BOSL2/std.scad>
module cubic_barbell(s=100, anchor=CENTER, spin=0, orient=UP) {
    override = [
                 [FWD,  [[0,-s/8,0], FWD+LEFT, 225]]
               ];
    attachable(anchor,spin,orient, size=[s*3,s,s],override=override) {
        union() {
            xcopies(2*s) cube(s, center=true);
            xcyl(h=2*s, d=s/4);
        }
        children();
    }
}
cubic_barbell(100) show_anchors(60);
```

In the above example we give three values for the override.  As
before, the first one places the anchor on the cylinder.  We have
added the second entry which points the anchor off to the left.
The third entry gives a spin override, whose effect is shown by the
position of the red flag on the arrow.  If you want to override all of
the x=0 anchors to be on the cylinder, with their standard directions,
you can do that by supplying a list: 

```openscad-3D;Big
include<BOSL2/std.scad>
module cubic_barbell(s=100, anchor=CENTER, spin=0, orient=UP) {
    override = [
                 for(j=[-1:1:1], k=[-1:1:1])
                   if ([j,k]!=[0,0]) [[0,j,k], [s/8*unit([0,j,k])]]
               ];
    attachable(anchor,spin,orient, size=[s*3,s,s],override=override) {
        union() {
            xcopies(2*s) cube(s, center=true);
            xcyl(h=2*s, d=s/4);
        }
        children();
    }
}
cubic_barbell(100) show_anchors(30);
```

Now all of the anchors in the middle are all rooted to the cylinder.  Another
way to do the same thing is to use a function literal for override.
It will be called with the anchor as its argument and needs to return undef to just use
the default, or a `[position, direction, spin]` triple to override the
default.  As before, you can omit values to keep their default.
Here is the same example using a function literal for the override:

```openscad-3D;Big
include<BOSL2/std.scad>
module cubic_barbell(s=100, anchor=CENTER, spin=0, orient=UP) {
    override = function (anchor) 
          anchor.x!=0 || anchor==CTR ? undef  // Keep these
        : [s/8*unit(anchor)];
    attachable(anchor,spin,orient, size=[s*3,s,s],override=override) {
        union() {
            xcopies(2*s) cube(s, center=true);
            xcyl(h=2*s, d=s/4);
        }
        children();
    }
}
cubic_barbell(100) show_anchors(30);
```

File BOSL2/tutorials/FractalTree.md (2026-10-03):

# Fractal Tree Tutorial

<!-- TOC -->

### Start with a Tree Trunk

Firstoff, include the BOSL2 library, then make a starting module that just has a tapered cylinder for the tree trunk.

```openscad-3D
include <BOSL2/std.scad>
module tree(l=1500, sc=0.7)
    cylinder(h=l, d1=l/5, d2=l/5*sc);
tree();
```

### Attaching a Branch

You can attach a branch to the top of the trunk by using `attach()` as a child of the trunk cylinder.

```openscad-3D
include <BOSL2/std.scad>
module tree(l=1500, sc=0.7)
    cylinder(h=l, d1=l/5, d2=l/5*sc)
        attach(TOP)
            yrot(30) cylinder(h=l*sc, d1=l/5*sc, d2=l/5*sc*sc);
tree();
```

### Replicating the Branch

Instead of attaching each branch individually, you can make multiple copies of one branch, that are rotated relative to each other.

```openscad-3D
include <BOSL2/std.scad>
module tree(l=1500, sc=0.7)
    cylinder(h=l, d1=l/5, d2=l/5*sc)
        attach(TOP)
            zrot_copies(n=2)  // Replicate that branch
                yrot(30) cylinder(h=l*sc, d1=l/5*sc, d2=l/5*sc*sc);
tree();
```

### Use Recursion

Since branches look much like the main trunk, we can make the tree recursive. Don't forget the termination clause, or else it'll try to recurse forever!

```openscad-Med
include <BOSL2/std.scad>
module tree(l=1500, sc=0.7, depth=10)
    cylinder(h=l, d1=l/5, d2=l/5*sc)
        attach(TOP)
            if (depth>0)  { // Important!
                zrot_copies(n=2)
                yrot(30) tree(depth=depth-1, l=l*sc, sc=sc);
            }
tree();
```

### Make it Not Flat

A flat planar tree isn't what we want, so lets bush it out a bit by rotating each level 90 degrees.

```openscad-Med
include <BOSL2/std.scad>
module tree(l=1500, sc=0.7, depth=10)
    cylinder(h=l, d1=l/5, d2=l/5*sc)
        attach(TOP)
            if (depth>0) {
                zrot(90)  // Bush it out
                zrot_copies(n=2)
                yrot(30) tree(depth=depth-1, l=l*sc, sc=sc);
            }
tree();
```

### Adding Leaves

Let's add leaves. They look much like squashed versions of the standard teardrop() module, so lets use that.

```openscad-Big
include <BOSL2/std.scad>
module tree(l=1500, sc=0.7, depth=10)
    cylinder(h=l, d1=l/5, d2=l/5*sc)
        attach(TOP)
            if (depth>0) {
                zrot(90)
                zrot_copies(n=2)
                yrot(30) tree(depth=depth-1, l=l*sc, sc=sc);
            } else {
                yscale(0.67)
                teardrop(d=l*3, l=1, anchor=BOT, spin=90);
            }
tree();
```

### Adding Color

We can finish this off with some color. The `color()` module will force all it's children and
their descendants to the new color, even if they were colored before. The `recolor()` module,
however, will only color children and decendants that don't already have a color set by a more
nested `recolor()`.

```openscad-Big
include <BOSL2/std.scad>
module tree(l=1500, sc=0.7, depth=10)
    recolor("lightgray")
    cylinder(h=l, d1=l/5, d2=l/5*sc)
        attach(TOP)
            if (depth>0) {
                zrot(90)
                zrot_copies(n=2)
                yrot(30) tree(depth=depth-1, l=l*sc, sc=sc);
            } else {
                recolor("springgreen")
                yscale(0.67)
                teardrop(d=l*3, l=1, anchor=BOT, spin=90);
            }
tree();
```

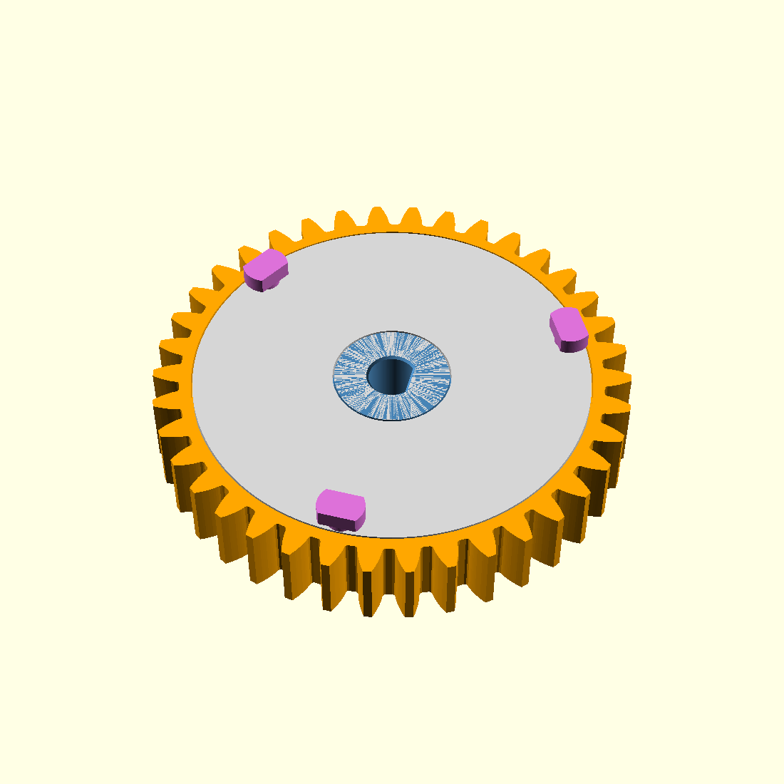
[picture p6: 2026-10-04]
motor_gear_38_hourglass_v2/motor_gear_38_hourglass_v2_assembly.png

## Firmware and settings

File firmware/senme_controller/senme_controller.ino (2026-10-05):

// ESP32 Dev Module (original ESP32 / WROOM), Arduino-ESP32 3.x.
// Active-high, low-side N-channel MOSFET drivers. See ../README.md.
#include <Arduino.h>
#include <Preferences.h>
#include <WiFi.h>
#include <esp_now.h>
#include <esp_wifi.h>
#include <driver/rmt_tx.h>
#include <esp_arduino_version.h>
#include <soc/soc_caps.h>
#include "Control.h"
#include "LedWaveform.h"

#if ESP_ARDUINO_VERSION_MAJOR < 3
#error "Use Arduino-ESP32 3.x."
#endif
#if !CONFIG_IDF_TARGET_ESP32
#error "This pin assignment and firmware target the original ESP32 (WROOM/DevKit)."
#endif

constexpr uint8_t LED_PIN = 25;
constexpr uint8_t MOTOR_PIN = 26;
constexpr uint8_t ENCODER_CLK_PIN = 32;
constexpr uint8_t ENCODER_DT_PIN = 33;
constexpr uint8_t BUTTON_PIN = 27;
// This controller appears to release LOW and press HIGH; verify with button logs.
// Use LOW for a conventional normally-open switch connected to GND.
constexpr uint8_t BUTTON_PRESSED_LEVEL = HIGH;
constexpr int ENCODER_DIRECTION = 1;  // Change to -1 if clockwise decreases.
constexpr int ENCODER_EDGES_PER_CLICK = 4;  // Some encoders need 2.
constexpr uint32_t MOTOR_PWM_HZ = 20000;
constexpr uint8_t MOTOR_PWM_BITS = 10;
constexpr uint32_t MOTOR_PWM_MAX = (1u << MOTOR_PWM_BITS) - 1;
constexpr uint32_t LED_BREATHE_PERIOD_US = 1000;  // 1 kHz dimming PWM.
constexpr uint8_t ESPNOW_CHANNEL = 1;  // Sender must use the same channel.

senme::Settings settings;
senme::Mode mode = senme::Mode::EspNow;
senme::Button button;
senme::SaveIndicator saveIndicator;
senme::ModeIndicator modeIndicator;
Preferences preferences;
bool storageReady = false;
bool motorReady = false;
uint32_t sequenceStartedAt = 0;
uint32_t editMotorStartedAt = 0;
float appliedMotorPercent = 0;
senme::MotorStop modeChangeStop;
unsigned lastPhase = 0;
portMUX_TYPE remoteMux = portMUX_INITIALIZER_UNLOCKED;
senme::RemoteRun remoteRun;

rmt_channel_handle_t ledChannel = nullptr;
rmt_encoder_handle_t ledEncoder = nullptr;
rmt_symbol_word_t ledSymbols[2]{};
bool ledEnabled = false;
uint32_t ledPeriodUs = 0;
uint32_t ledOnUs = 0;
bool ledDimBlink = false;

portMUX_TYPE encoderMux = portMUX_INITIALIZER_UNLOCKED;
volatile uint8_t encoderPrevious = 0;
volatile int encoderEdges = 0;
volatile int encoderClicks = 0;

void ARDUINO_ISR_ATTR encoderChanged() {
  portENTER_CRITICAL_ISR(&encoderMux);
  const uint8_t current = (digitalRead(ENCODER_CLK_PIN) << 1) | digitalRead(ENCODER_DT_PIN);
  const uint8_t previous = encoderPrevious;
  encoderPrevious = current;
  if ((previous ^ current) == 3) {
    encoderEdges = 0;  // Both contacts changed: discard an ambiguous transition.
  } else if (previous != current) {
    // Adjacent contact bounce reverses the previous edge and cancels itself.
    encoderEdges = encoderEdges + (((previous & 1) ^ (current >> 1)) ? 1 : -1);
    if (encoderEdges >= ENCODER_EDGES_PER_CLICK) {
      if (encoderClicks < 10000) encoderClicks = encoderClicks + 1;
      encoderEdges = 0;
    } else if (encoderEdges <= -ENCODER_EDGES_PER_CLICK) {
      if (encoderClicks > -10000) encoderClicks = encoderClicks - 1;
      encoderEdges = 0;
    }
  }
  portEXIT_CRITICAL_ISR(&encoderMux);
}

void fail(const char* message) {
  // Latch the fault: no START or mode transition can resume operation.
  portENTER_CRITICAL(&remoteMux);
  remoteRun.disable();
  portEXIT_CRITICAL(&remoteMux);
  Serial.printf("ERROR: %s; attempting controlled motor stop.\n", message);

  // Use only direct API calls here; check()/fail() must never recurse.
  // Start from the last successfully applied output, not the failed request.
  senme::MotorStop faultStop;
  faultStop.begin(millis(), appliedMotorPercent);
  bool rampWriteFailed = false;
  if (motorReady) {
    while (faultStop.active() && !faultStop.due(millis())) {
      const uint32_t duty = lroundf(faultStop.output(millis()) * MOTOR_PWM_MAX / 100.0f);
      if (ledcWrite(MOTOR_PIN, duty)) {
        appliedMotorPercent = duty * 100.0f / MOTOR_PWM_MAX;
      } else {
        rampWriteFailed = true;
      }
      delay(10);
    }
  }
  bool zeroAccepted = motorReady ? ledcWrite(MOTOR_PIN, 0) : true;
  if (!motorReady) digitalWrite(MOTOR_PIN, LOW);
  if (zeroAccepted) appliedMotorPercent = 0;
  if (ledChannel && ledEnabled) rmt_disable(ledChannel);
  pinMode(LED_PIN, OUTPUT);
  digitalWrite(LED_PIN, LOW);
  if (rampWriteFailed) Serial.println("ERROR: motor ramp write failed; smooth deceleration not confirmed.");
  Serial.println(zeroAccepted ? "FAULT LATCHED: motor zero command accepted; reset required."
                              : "FAULT LATCHED: motor zero command failed; retrying; reset required.");
  while (true) {
    delay(1000);
    // If the API recovers, keep requesting OFF; never restart the ramp or run.
    if (!zeroAccepted && ledcWrite(MOTOR_PIN, 0)) {
      zeroAccepted = true;
      appliedMotorPercent = 0;
      Serial.println("FAULT LATCHED: motor zero command accepted; reset required.");
    }
  }
}

void check(esp_err_t result, const char* operation) {
  if (result != ESP_OK) fail(operation);
}

void receiveEspNow(const esp_now_recv_info_t*, const uint8_t* data, int length) {
  portENTER_CRITICAL(&remoteMux);
  remoteRun.receive(data, length);
  portEXIT_CRITICAL(&remoteMux);
}

void beginEspNow() {
  if (!WiFi.mode(WIFI_STA)) fail("Wi-Fi station initialization");
  check(esp_wifi_set_channel(ESPNOW_CHANNEL, WIFI_SECOND_CHAN_NONE), "ESP-NOW channel");
  check(esp_now_init(), "ESP-NOW initialization");
  check(esp_now_register_recv_cb(receiveEspNow), "ESP-NOW receive callback");
  Serial.printf("ESP-NOW: MAC=%s channel=%u command=START\n",
                WiFi.macAddress().c_str(), ESPNOW_CHANNEL);
}

void writeLed(uint32_t periodUs, uint32_t onUs, bool dimBlink = false) {
  if (periodUs == ledPeriodUs && onUs == ledOnUs && dimBlink == ledDimBlink) return;
  if (ledEnabled) {
    check(rmt_disable(ledChannel), "LED stop previous waveform");
    ledEnabled = false;
  }
  rmt_carrier_config_t carrier = {};
  carrier.frequency_hz = senme::kBlinkCarrierHz;
  carrier.duty_cycle = senme::kBlinkLedDuty;
  check(rmt_apply_carrier(ledChannel, dimBlink && senme::kBlinkLedDuty < 1.0f ? &carrier : nullptr), "LED carrier");
  check(rmt_encoder_reset(ledEncoder), "LED encoder reset");
  const auto envelope = senme::ledEnvelope(periodUs, onUs);
  for (unsigned i = 0; i < envelope.count / 2; ++i) {
    ledSymbols[i].duration0 = envelope.pulses[2 * i].duration;
    ledSymbols[i].level0 = envelope.pulses[2 * i].high;
    ledSymbols[i].duration1 = envelope.pulses[2 * i + 1].duration;
    ledSymbols[i].level1 = envelope.pulses[2 * i + 1].high;
  }
  check(rmt_enable(ledChannel), "LED enable");
  ledEnabled = true;
  rmt_transmit_config_t transmit = {};
  transmit.loop_count = -1;
  transmit.flags.queue_nonblocking = true;
  check(rmt_transmit(ledChannel, ledEncoder, ledSymbols,
                    envelope.count / 2 * sizeof(ledSymbols[0]), &transmit), "LED waveform");
  ledPeriodUs = periodUs;
  ledOnUs = onUs;
  ledDimBlink = dimBlink;
}

void forceLed(int level) {
  writeLed(LED_BREATHE_PERIOD_US, level > 0 ? LED_BREATHE_PERIOD_US : 0);
}

void beginLed() {
  rmt_tx_channel_config_t channel = {};
  channel.gpio_num = gpio_num_t(LED_PIN);
  channel.clk_src = RMT_CLK_SRC_DEFAULT;
  channel.resolution_hz = 1000000;
  channel.mem_block_symbols = 64;
  channel.trans_queue_depth = 1;
  check(rmt_new_tx_channel(&channel, &ledChannel), "LED RMT channel");
  rmt_copy_encoder_config_t encoder = {};
  check(rmt_new_copy_encoder(&encoder, &ledEncoder), "LED RMT encoder");
  forceLed(0);
}

void reportSettings() {
  Serial.printf("LED: %.2f ms ON / %.2f ms period; motor maximum: %lu%%\n",
                settings.ledOnUs / 1000.0, senme::kBlinkPeriodUs / 1000.0, static_cast<unsigned long>(settings.motorPercent));
}

void enterNextMode(uint32_t now) {
  if (modeChangeStop.active()) {
    Serial.println("Mode change ignored while motor is stopping");
    return;
  }
  portENTER_CRITICAL(&remoteMux);
  const bool busy = remoteRun.busy();
  if (!busy) remoteRun.disable();
  portEXIT_CRITICAL(&remoteMux);
  if (busy) {
    Serial.println("ESP-NOW: mode change ignored during run/stop");
    return;
  }
  portENTER_CRITICAL(&encoderMux);
  encoderClicks = 0;
  encoderEdges = 0;
  portEXIT_CRITICAL(&encoderMux);
  switch (mode) {
    case senme::Mode::Sequence:
      modeChangeStop.begin(now, appliedMotorPercent);
      mode = senme::Mode::EditLed;
      Serial.println("Mode: EDIT 1 (LED on-time); motor stopping over 15 seconds");
      break;
    case senme::Mode::EditLed:
      mode = senme::Mode::EditMotor;
      editMotorStartedAt = now;
      Serial.println("Mode: EDIT 2 (motor maximum); ramp up over 15 seconds");
      break;
    case senme::Mode::EditMotor:
      mode = senme::Mode::EspNow;
      portENTER_CRITICAL(&remoteMux);
      remoteRun.stopEditing(now, appliedMotorPercent);
      portEXIT_CRITICAL(&remoteMux);
      Serial.println("Mode: ESP-NOW; stopping edit motor over 15 seconds to 45%, then OFF");
      break;
    case senme::Mode::EspNow:
      mode = senme::Mode::Sequence;
      sequenceStartedAt = now;
      lastPhase = 0;
      Serial.println("Mode: SEQUENCE (restart from phase 1)");
      break;
  }
  // Rejected clicks return above; only accepted transitions get feedback.
  saveIndicator.cancel();
  modeIndicator.begin(now);
  reportSettings();
}

void saveCurrentSetting() {
  if (!senme::isEditing(mode)) return;
  if (!storageReady) {
    Serial.println("SAVE FAILED: NVS unavailable; current setting remains in RAM only.");
    return;
  }
  const char* key = mode == senme::Mode::EditLed ? "ledOnUs" : "motorPct";
  const uint32_t value = mode == senme::Mode::EditLed ? settings.ledOnUs : settings.motorPercent;
  if (preferences.putUInt(key, value) != sizeof(uint32_t)) {
    Serial.println("SAVE FAILED: setting remains in RAM only.");
    return;
  }
  Serial.printf("SAVED: %s = %lu\n", key, static_cast<unsigned long>(value));
  modeIndicator.cancel();
  saveIndicator.begin(millis());
}

void setup() {
  pinMode(LED_PIN, OUTPUT);
  pinMode(MOTOR_PIN, OUTPUT);
  digitalWrite(LED_PIN, LOW);
  digitalWrite(MOTOR_PIN, LOW);
  Serial.begin(115200);
  pinMode(ENCODER_CLK_PIN, INPUT_PULLUP);
  pinMode(ENCODER_DT_PIN, INPUT_PULLUP);
  pinMode(BUTTON_PIN, INPUT_PULLUP);
  Serial.printf("BUTTON: GPIO27=%d; pressed level=%d (HIGH=1, LOW=0)\n",
                digitalRead(BUTTON_PIN), BUTTON_PRESSED_LEVEL);

  storageReady = preferences.begin("senme", false);
  if (storageReady) {
    settings.ledOnUs = preferences.getUInt("ledOnUs", settings.ledOnUs);
    settings.motorPercent = preferences.getUInt("motorPct", settings.motorPercent);
    settings.validate();
  } else {
    Serial.println("NVS unavailable: using defaults; saving disabled.");
  }
  motorReady = ledcAttach(MOTOR_PIN, MOTOR_PWM_HZ, MOTOR_PWM_BITS);
  if (!motorReady) fail("Motor PWM initialization");
  if (!ledcWrite(MOTOR_PIN, 0)) fail("Motor initial off");
  beginLed();
  beginEspNow();
  encoderPrevious = (digitalRead(ENCODER_CLK_PIN) << 1) | digitalRead(ENCODER_DT_PIN);
  attachInterrupt(digitalPinToInterrupt(ENCODER_CLK_PIN), encoderChanged, CHANGE);
  attachInterrupt(digitalPinToInterrupt(ENCODER_DT_PIN), encoderChanged, CHANGE);
  sequenceStartedAt = millis();
  Serial.println("Mode: ESP-NOW; click: next mode; hold 3 seconds in edit mode: save");
  reportSettings();
  // Hardware is initialized and the motor is off before accepting START.
  portENTER_CRITICAL(&remoteMux);
  remoteRun.enable(millis());
  portEXIT_CRITICAL(&remoteMux);
  Serial.println("ESP-NOW: READY (waiting for START)");
}

void loop() {
  const uint32_t now = millis();
  // Rebase each cycle so millis() rollover cannot disturb the 110-second cycle.
  while (uint32_t(now - sequenceStartedAt) >= senme::kCycleMs) {
    sequenceStartedAt += senme::kCycleMs;
  }
  const auto event = button.update(digitalRead(BUTTON_PIN) == BUTTON_PRESSED_LEVEL, now);
  if (button.samplingInterrupted()) {
    Serial.println("BUTTON: sampling gap >100ms; gesture discarded; release and press again");
  }
  if (event != senme::ButtonEvent::None) {
    Serial.printf("BUTTON: %s (%lu ms)\n",
                  event == senme::ButtonEvent::Click ? "CLICK" : "LONG PRESS",
                  static_cast<unsigned long>(button.lastPressMs()));
  }
  if (event == senme::ButtonEvent::Click) enterNextMode(now);

  portENTER_CRITICAL(&encoderMux);
  const int clicks = encoderClicks * ENCODER_DIRECTION;
  encoderClicks = 0;
  portEXIT_CRITICAL(&encoderMux);
  if (clicks != 0 && senme::isEditing(mode)) {
    settings.adjust(mode, clicks);
    reportSettings();
  }

  portENTER_CRITICAL(&remoteMux);
  const auto oldRemoteState = remoteRun.state();
  remoteRun.tick(now);
  const auto remoteSnapshot = remoteRun;
  portEXIT_CRITICAL(&remoteMux);
  if (oldRemoteState == senme::RemoteRun::State::Pending) {
    saveIndicator.cancel();
    modeIndicator.cancel();
    Serial.println("ESP-NOW: START accepted; 6 flashes (1 second), motor OFF");
  }
  if (oldRemoteState == senme::RemoteRun::State::Notifying &&
      remoteSnapshot.state() == senme::RemoteRun::State::Running) {
    Serial.println("ESP-NOW: RUNNING (60 seconds)");
  }
  if (oldRemoteState == senme::RemoteRun::State::Cooldown &&
      remoteSnapshot.state() == senme::RemoteRun::State::Ready) {
    Serial.println("ESP-NOW: READY (waiting for START)");
  }

  auto output = mode == senme::Mode::EspNow
                          ? remoteSnapshot.output(now, settings)
                          : senme::outputFor(mode, mode == senme::Mode::EditMotor
                              ? now - editMotorStartedAt : now - sequenceStartedAt, settings);
  if (modeChangeStop.active()) output.motorPercent = modeChangeStop.output(now);
  const uint32_t motorDuty = lroundf(output.motorPercent * MOTOR_PWM_MAX / 100.0f);
  static uint32_t previousMotorDuty = 0;
  if (motorDuty != previousMotorDuty) {
    if (!ledcWrite(MOTOR_PIN, motorDuty)) fail("Motor duty update");
    previousMotorDuty = motorDuty;
  }
  if (modeChangeStop.due(now)) modeChangeStop.finish();
  appliedMotorPercent = motorDuty * 100.0f / MOTOR_PWM_MAX;
  // Saturate the edit ramp clock to avoid restarting it at millis() rollover.
  if (mode == senme::Mode::EditMotor && uint32_t(now - editMotorStartedAt) >= senme::kMotorRampMs) {
    editMotorStartedAt = now - senme::kMotorRampMs;
  }
  const int saveLevel = saveIndicator.level(now);
  const int modeLevel = modeIndicator.level(now);
  if (saveLevel >= 0) {
    // Indicator pulses retain full brightness; motor control continues.
    forceLed(saveLevel);
  } else if (modeLevel >= 0) {
    forceLed(modeLevel);
  } else if (output.led == senme::LedPattern::Off) {
    writeLed(senme::kBlinkPeriodUs, 0);
  } else if (output.led == senme::LedPattern::Breathe ||
             output.led == senme::LedPattern::Steady) {
    writeLed(LED_BREATHE_PERIOD_US, lroundf(output.brightness * LED_BREATHE_PERIOD_US));
  } else {
    writeLed(senme::kBlinkPeriodUs, settings.ledOnUs, true);
  }
  if (mode == senme::Mode::EspNow && remoteSnapshot.editStopDue(now)) {
    portENTER_CRITICAL(&remoteMux);
    remoteRun.confirmEditStopped(millis());
    portEXIT_CRITICAL(&remoteMux);
    Serial.println("ESP-NOW: READY (waiting for START)");
  }
  if (mode == senme::Mode::EspNow && remoteSnapshot.stopDue(now)) {
    portENTER_CRITICAL(&remoteMux);
    remoteRun.confirmStopped(millis());
    portEXIT_CRITICAL(&remoteMux);
    Serial.println("ESP-NOW: STOPPED; COOLDOWN (3 seconds; START ignored)");
  }
  if (mode == senme::Mode::Sequence && output.phase != lastPhase) {
    lastPhase = output.phase;
    Serial.printf("Sequence phase: %u\n", output.phase);
  }
  // Saving never happens in an ISR. Hardware PWM keeps running during NVS writes.
  if (event == senme::ButtonEvent::LongPress) saveCurrentSetting();
  delay(1);
}

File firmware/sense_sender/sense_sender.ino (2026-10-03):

// ESP32-WROOM / Arduino-ESP32 3.3.8. MPU6050 acceleration -> ESP-NOW START.
#include <Arduino.h>
#include <Wire.h>
#include <WiFi.h>
#include <esp_now.h>
#include <esp_wifi.h>
#include "ShakeDetector.h"

constexpr int SDA_PIN = 21;
constexpr int SCL_PIN = 22;
constexpr uint8_t MPU_ADDRESS = 0x68;  // AD0=GND; use 0x69 for AD0=3.3V.
constexpr uint8_t ESPNOW_CHANNEL = 1;
// Broadcast by default. Replace with the receiver STA MAC for a single receiver.
const uint8_t RECEIVER_MAC[6] = {0xFF, 0xFF, 0xFF, 0xFF, 0xFF, 0xFF};
constexpr uint32_t SAMPLE_MS = 10;

sense::ShakeDetector detector;
uint32_t sampledAt = 0;
uint32_t reportedAt = 0;
bool sensorError = false;
portMUX_TYPE sendMux = portMUX_INITIALIZER_UNLOCKED;
int sendResult = -1;

void fail(const char* message) {
  Serial.printf("ERROR: %s; sending disabled. Check wiring/configuration and reset.\n", message);
  while (true) delay(1000);
}

void check(esp_err_t result, const char* message) {
  if (result != ESP_OK) fail(message);
}

bool writeRegister(uint8_t reg, uint8_t value) {
  Wire.beginTransmission(MPU_ADDRESS);
  Wire.write(reg);
  Wire.write(value);
  return Wire.endTransmission() == 0;
}

bool readRegisters(uint8_t reg, uint8_t* data, size_t length) {
  Wire.beginTransmission(MPU_ADDRESS);
  Wire.write(reg);
  if (Wire.endTransmission(false) != 0) return false;
  if (Wire.requestFrom(MPU_ADDRESS, length, true) != length) {
    while (Wire.available()) Wire.read();
    return false;
  }
  for (size_t i = 0; i < length; ++i) data[i] = Wire.read();
  return true;
}

void beginMpu() {
  if (!Wire.begin(SDA_PIN, SCL_PIN, 100000)) fail("I2C initialization");
  Wire.setTimeOut(20);
  uint8_t identity = 0;
  if (!readRegisters(0x75, &identity, 1) || identity != 0x68) fail("MPU6050 WHO_AM_I (expected 0x68)");
  if (!writeRegister(0x6B, 0x80)) fail("MPU6050 reset");
  delay(100);
  // Wake with X-gyro PLL; all axes enabled; DLPF 44 Hz; 100 Hz sampling; +/-8 g.
  if (!writeRegister(0x6B, 0x01) || !writeRegister(0x6C, 0x00) ||
      !writeRegister(0x1A, 0x03) || !writeRegister(0x19, 9) ||
      !writeRegister(0x1C, 0x10)) fail("MPU6050 configuration");
  delay(100);
}

float accelerationG(const uint8_t* bytes) {
  const uint16_t raw = (uint16_t(bytes[0]) << 8) | bytes[1];
  const int32_t signedRaw = raw < 0x8000 ? int32_t(raw) : int32_t(raw) - 65536;
  return signedRaw / 4096.0f;
}

void sentEspNow(const esp_now_send_info_t*, esp_now_send_status_t status) {
  portENTER_CRITICAL(&sendMux);
  sendResult = status == ESP_NOW_SEND_SUCCESS ? 1 : 0;
  portEXIT_CRITICAL(&sendMux);
}

void setup() {
  Serial.begin(115200);
  beginMpu();
  if (!WiFi.mode(WIFI_STA)) fail("Wi-Fi station initialization");
  check(esp_wifi_set_channel(ESPNOW_CHANNEL, WIFI_SECOND_CHAN_NONE), "Wi-Fi channel");
  check(esp_now_init(), "ESP-NOW initialization");
  esp_now_peer_info_t peer = {};
  memcpy(peer.peer_addr, RECEIVER_MAC, sizeof(RECEIVER_MAC));
  peer.channel = ESPNOW_CHANNEL;
  peer.ifidx = WIFI_IF_STA;
  peer.encrypt = false;
  check(esp_now_add_peer(&peer), "ESP-NOW peer registration");
  check(esp_now_register_send_cb(sentEspNow), "ESP-NOW send callback");
  Serial.printf("sense_sender: MAC=%s channel=%u target=%02X:%02X:%02X:%02X:%02X:%02X\n",
                WiFi.macAddress().c_str(), ESPNOW_CHANNEL,
                RECEIVER_MAC[0], RECEIVER_MAC[1], RECEIVER_MAC[2],
                RECEIVER_MAC[3], RECEIVER_MAC[4], RECEIVER_MAC[5]);
  Serial.printf("MPU6050: SDA=%d SCL=%d address=0x%02X; threshold=%.2f g\n",
                SDA_PIN, SCL_PIN, MPU_ADDRESS, sense::kTriggerG);
  Serial.println("Keep still for 3 seconds to arm; shake strongly to send START.");
}

void loop() {
  portENTER_CRITICAL(&sendMux);
  const int result = sendResult;
  sendResult = -1;
  portEXIT_CRITICAL(&sendMux);
  if (result >= 0) Serial.printf("ESP-NOW: link %s (not execution acknowledgement)\n", result ? "OK" : "FAILED");

  const uint32_t now = millis();
  if (uint32_t(now - sampledAt) < SAMPLE_MS) {
    delay(1);
    return;
  }
  sampledAt = now;
  uint8_t data[6];
  if (!readRegisters(0x3B, data, sizeof(data))) {
    detector.invalidate();
    if (!sensorError) Serial.println("MPU6050: read failed; sending disabled until valid readings and quiet period");
    sensorError = true;
    return;
  }
  if (sensorError) Serial.println("MPU6050: readings recovered; keep still to rearm");
  sensorError = false;
  const bool wasArmed = detector.armed();
  if (detector.update(accelerationG(data), accelerationG(data + 2), accelerationG(data + 4), now)) {
    const uint8_t command[] = {'S', 'T', 'A', 'R', 'T'};
    const esp_err_t err = esp_now_send(RECEIVER_MAC, command, sizeof(command));
    Serial.printf("SHAKE: %.2f g; START %s (%s)\n", detector.strengthG(),
                  err == ESP_OK ? "queued" : "failed", esp_err_to_name(err));
    // No retries: a late retry could start an unintended second receiver cycle.
  } else if (!wasArmed && detector.armed()) {
    Serial.println("ARMED: waiting for shake");
  }
  if (uint32_t(now - reportedAt) >= 500) {
    reportedAt = now;
    Serial.printf("motion=%.2f g; %s\n", detector.strengthG(), detector.armed() ? "ARMED" : "WAIT QUIET");
  }
}

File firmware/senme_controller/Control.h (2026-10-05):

#pragma once

#include <cmath>
#include <cstdint>
#include <cstring>

namespace senme {

constexpr uint32_t kBlinkPeriodUs = 55550;
constexpr uint32_t kOnStepUs = 500;
constexpr uint32_t kCycleMs = 110000;
constexpr uint32_t kMotorRampMs = 15000;
constexpr uint32_t kEditStopMs = kMotorRampMs;
constexpr float kMotorStartPercent = 55.0f;
constexpr float kEditStopPercent = 55.0f;
constexpr uint32_t kLongPressMs = 3000;
constexpr uint32_t kDebounceMs = 25;
constexpr uint32_t kButtonMaxSampleGapMs = 100;

enum class Mode { Sequence, EditLed, EditMotor, EspNow };
enum class LedPattern { Breathe, Steady, Blink, Off };

// Override the LED for one second after a successful save; -1 restores normal output.
class SaveIndicator {
 public:
  void cancel() { active_ = false; }
  void begin(uint32_t now) { startedAt_ = now; active_ = true; }
  int level(uint32_t now) {
    if (!active_) return -1;
    const uint32_t elapsed = now - startedAt_;
    if (elapsed >= 1000) {
      active_ = false;
      return -1;
    }
    return (elapsed * 6 / 1000) % 2 == 0 ? 1 : 0;
  }
 private:
  uint32_t startedAt_ = 0;
  bool active_ = false;
};
// Two quick flashes after an accepted mode change. Start with OFF so the
// flashes remain distinguishable when the previous mode had the LED ON.
// OFF 100 / ON 80 / OFF 100 / ON 80 / OFF 140 ms; -1 resumes normal output.
class ModeIndicator {
 public:
  void begin(uint32_t now) { startedAt_ = now; active_ = true; }
  void cancel() { active_ = false; }
  int level(uint32_t now) {
    if (!active_) return -1;
    const uint32_t elapsed = now - startedAt_;
    if (elapsed >= 500) {
      active_ = false;
      return -1;
    }
    return (elapsed >= 100 && elapsed < 180) ||
           (elapsed >= 280 && elapsed < 360) ? 1 : 0;
  }
 private:
  uint32_t startedAt_ = 0;
  bool active_ = false;
};
enum class ButtonEvent { None, Click, LongPress };

inline bool isEditing(Mode mode) {
  return mode == Mode::EditLed || mode == Mode::EditMotor;
}

struct Settings {
  uint32_t ledOnUs = 5000;
  uint32_t motorPercent = uint32_t(kMotorStartPercent);

  void validate() {
    if (ledOnUs == 56000) ledOnUs = kBlinkPeriodUs; // Preserve legacy continuous-on setting.
    if (ledOnUs > kBlinkPeriodUs ||
        (ledOnUs != kBlinkPeriodUs && ledOnUs % kOnStepUs != 0)) ledOnUs = 5000;
    if (motorPercent > 100) motorPercent = uint32_t(kMotorStartPercent);
  }

  void adjust(Mode mode, int clicks) {
    if (!isEditing(mode)) return;
    // The continuous-on endpoint is between the regular 0.5 ms steps.
    const uint32_t ledBase = ledOnUs == kBlinkPeriodUs && clicks < 0
        ? ((kBlinkPeriodUs + kOnStepUs - 1) / kOnStepUs) * kOnStepUs : ledOnUs;
    int64_t value = mode == Mode::EditLed
                        ? int64_t(ledBase) + int64_t(clicks) * kOnStepUs
                        : int64_t(motorPercent) + clicks;
    const int64_t maximum = mode == Mode::EditLed ? kBlinkPeriodUs : 100;
    if (value < 0) value = 0;
    if (value > maximum) value = maximum;
    if (mode == Mode::EditLed) ledOnUs = uint32_t(value);
    else motorPercent = uint32_t(value);
  }
};

struct Output {
  LedPattern led;
  float brightness;
  float motorPercent;
  unsigned phase;
};

inline Output breatheOutput(uint32_t elapsedMs) {
  // A sine wave shifted by -pi/2: starts and ends at zero brightness.
  const float phase = 6.28318530718f * float(elapsedMs % 5000) / 5000.0f;
  return {LedPattern::Breathe, 0.5f - 0.5f * std::cos(phase), 0, 1};
}

inline Output startingOutput(uint32_t elapsedMs, const Settings& settings, unsigned phase) {
  const float target = float(settings.motorPercent);
  const float from = target < kMotorStartPercent ? target : kMotorStartPercent;
  return {LedPattern::Steady, float(elapsedMs) / kMotorRampMs,
          from + (target - from) * float(elapsedMs) / kMotorRampMs, phase};
}

// Hold outputs already at/below the cutoff; never accelerate to reach 55%.
inline float stoppingPercent(float from, uint32_t elapsedMs) {
  if (elapsedMs >= kMotorRampMs) return 0;
  const float cutoff = from < kEditStopPercent ? from : kEditStopPercent;
  return from + (cutoff - from) * float(elapsedMs) / kMotorRampMs;
}

class MotorStop {
 public:
  void begin(uint32_t now, float from) {
    startedAt_ = now;
    from_ = from;
    active_ = from > 0;
  }
  bool active() const { return active_; }
  bool due(uint32_t now) const { return active_ && uint32_t(now - startedAt_) >= kMotorRampMs; }
  float output(uint32_t now) const { return active_ ? stoppingPercent(from_, now - startedAt_) : 0; }
  void finish() { active_ = false; }
 private:
  bool active_ = false;
  uint32_t startedAt_ = 0;
  float from_ = 0;
};

inline Output outputFor(Mode mode, uint32_t elapsedMs, const Settings& settings) {
  if (mode == Mode::EspNow) return {LedPattern::Off, 0, 0, 0};
  if (mode == Mode::EditLed) return {LedPattern::Blink, 0, 0, 0};
  if (mode == Mode::EditMotor) {
    if (elapsedMs < kMotorRampMs) return startingOutput(elapsedMs, settings, 0);
    return {LedPattern::Blink, 0, float(settings.motorPercent), 0};
  }
  const uint32_t t = elapsedMs % kCycleMs;
  if (t < 20000) {
    return breatheOutput(t);
  }
  if (t < 20000 + kMotorRampMs) {
    return startingOutput(t - 20000, settings, 2);
  }
  if (t < kCycleMs - kMotorRampMs) return {LedPattern::Blink, 0, float(settings.motorPercent), 3};
  return {LedPattern::Blink, 0, stoppingPercent(float(settings.motorPercent), t - (kCycleMs - kMotorRampMs)), 4};
}

constexpr uint32_t kRemoteNotifyMs = 1000;
constexpr uint32_t kRemoteRunMs = 60000;
constexpr uint32_t kRemoteCooldownMs = 3000;
constexpr uint32_t kRemoteRampMs = kMotorRampMs;
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

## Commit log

2026-10-03 Initial public release of senme designs and firmware
    [BOSL2logo.scad, affine.scad, annular_sector_86.scad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]
2026-10-04 Publish current senme project from the correct workspace
    [annular_sector_86.stl, body.stl, box.stl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]
2026-10-05 feat(firmware): flash LED six times before remote motor start
2026-10-06 fix(firmware): shorten sequence hold to 30 seconds
    [Control.h, control_test.cpp, senme_controller.ino]
